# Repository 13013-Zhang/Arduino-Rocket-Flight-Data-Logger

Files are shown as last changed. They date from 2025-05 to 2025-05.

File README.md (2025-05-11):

**Read this in other languages: [English](README.md), [中文](README_ZH.md).**

# 🚀 Arduino-Based Water Rocket Flight Data Logger

An Arduino-powered, high-precision water rocket system designed to collect and log complete flight data from launch to landing. The system uses sensor fusion and filtering algorithms, features automatic parachute deployment, and includes an audio signal upon landing. Compatible with the real-time data visualization platform.

## 🧠 Features

- Sensor fusion using **MPU6050 (I2C)** and **BME280 (SPI)** for flight dynamics and environment data
- **Kalman filter** for angle estimation and **BMP (barometric method)** for altitude correction
- **Millisecond-interval data logging** to SD card with uniform timestamps for detailed analysis
- Real-time data visualization support
- **Automatic parachute deployment** at apogee or when the rocket tilts more than 120° (confirmed 3 times to avoid false triggers)
- **Buzzer alert** activated upon landing to assist in rocket retrieval

## 🛠️ Hardware Wiring
```
MPU6050: (I2C)
VCC      -> 3.3V
SCL      -> A5
SDA      -> A4
AD0      -> GND

BME280: (SPI)
VCC  -> 3.3V
SCK  -> D13
MISO -> D12
MOSI -> D11
CS   -> D9

SD Card: (SPI)
VCC  -> 5V
CS   -> D10
MOSI -> D11
MISO -> D12
SCK  -> D13

Servo:
PWM  -> D3
VCC  -> 5V
GND  -> GND

Buzzer:
+    -> D2
GND  -> GND 

LM35:
OUT -> A0
VCC -> 5V
GND -> GND
```

## 📦 Software Capabilities

- ✅ Real-time logging of: orientation angles (x, y, z), acceleration, pressure, altitude, temperature, and timestamp  
- ✅ Kalman filtering for stable angle output from MPU6050  
- ✅ BMP correction for accurate altitude using BME280  
- ✅ Apogee and tilt-based parachute logic (60° open, 90° closed)  
- ✅ Buzzer activation after landing (based on altitude and motion detection)  
- ✅ All data saved in CSV format on SD card  
- ✅ Compatible with Vofa+ desktop tool for visualization

## 📂 Data Format (Saved on SD Card)

Example (logged at consistent millisecond intervals):
| Time(ms) | Temp(C) | Pressure(hPa) | Alt(m) | FiltAlt(m) | AccX(g) | AccY(g) | AccZ(g) | GyroX(deg/s) | GyroY(deg/s) | GyroZ(deg/s) | AngleX(deg) | AngleY(deg) | AngleZ(deg) | LM35Temp(C) |
|---|---|---|---|---|---|---|---|---|---|---|---|---|---|---|
| 0 | 21.94 | 1013.11 | 0.55 | 0.11 | 0 | -0.04 | 0.98 | 1.84 | -2.7 | 2.32 | 2.67 | -4.63 | 3.8 | 21.48 |

## ✅ Development & Compatibility

- IDE: Arduino IDE  
- All libraries can be installed via Library Manager  
- Supported Boards: Arduino UNO / Nano / Mega etc.  
- Upper Computer: Vofa+  

## 📸 Images and Demonstrations
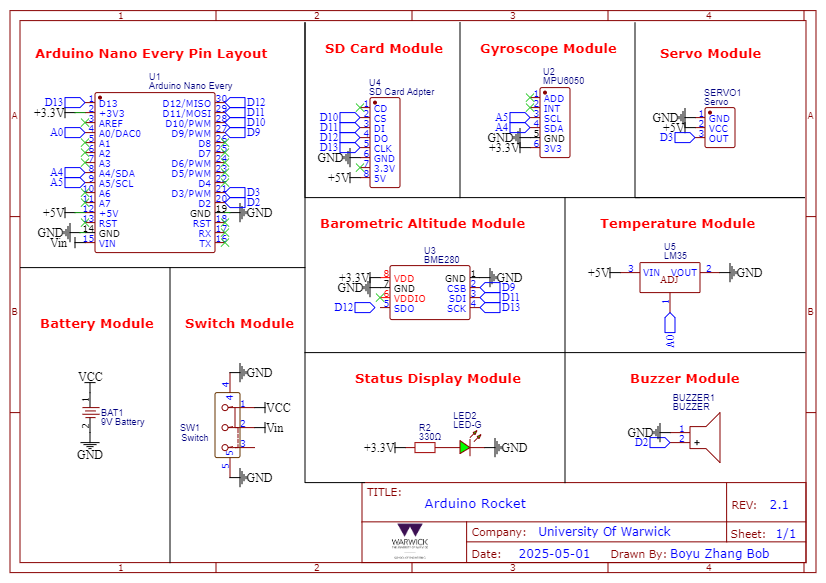
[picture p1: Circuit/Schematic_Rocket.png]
Schematic

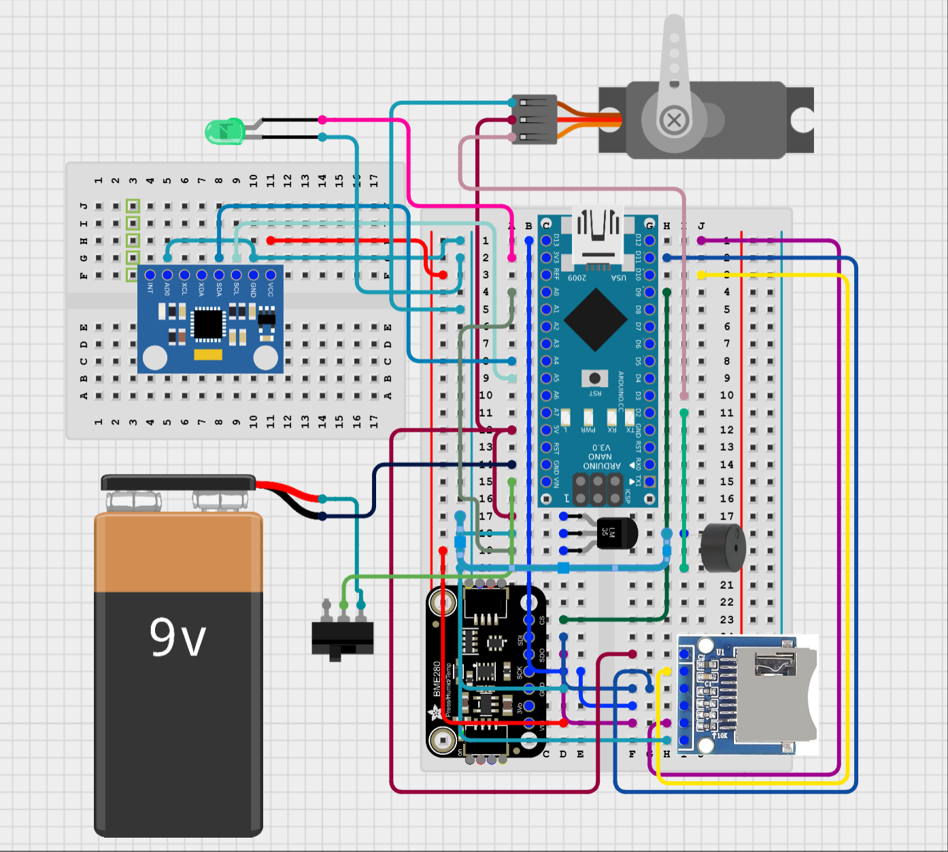
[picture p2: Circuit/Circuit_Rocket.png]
Circuit

<video controls src="Demonstration/Vofa+.mp4" title="Title"></video>

---

## 📄 License

This project is open-sourced under the MIT License. Feel free to use and modify it. Please provide attribution for commercial use.

---

## 🙌 Acknowledgments

This project was developed as part of the **ES192 Engineering Design** course at the **University of Warwick**.

Special thanks to my brilliant teammates for their dedication, teamwork, and creativity throughout the design, development, and testing phases:

- NGUYEN, Ryan  
- NIE, Jingren  
- CHAN, Rooney  
- JONES, Morgan  
- AL-DABAGH, Mouaid  
- HAQUE, Mayiz
- Boyu Zhang Bob (me)

We also extend our gratitude to the open-source hardware and software communities, whose tools and resources made this project possible.

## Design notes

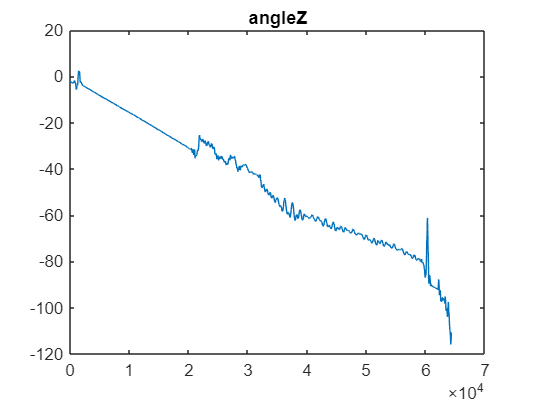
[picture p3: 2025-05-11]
Plots/angleZ.png

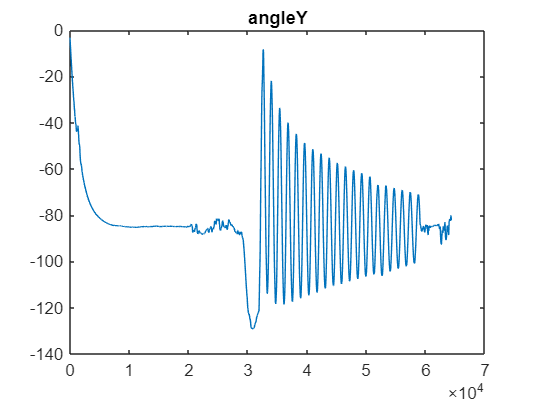
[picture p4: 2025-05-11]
Plots/AngleY.png

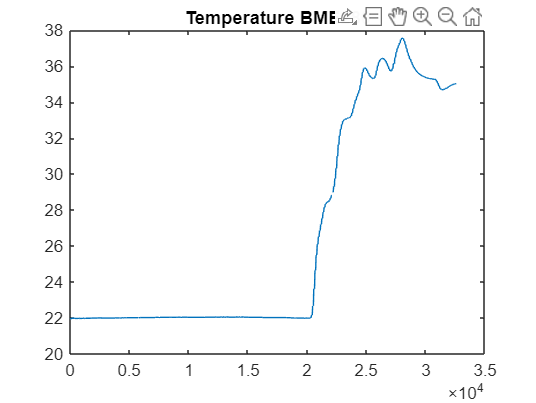
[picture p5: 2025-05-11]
Plots/Temperture BME.png

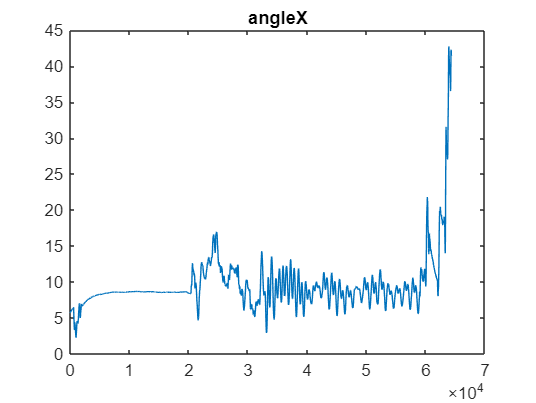
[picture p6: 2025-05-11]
Plots/angleX.png

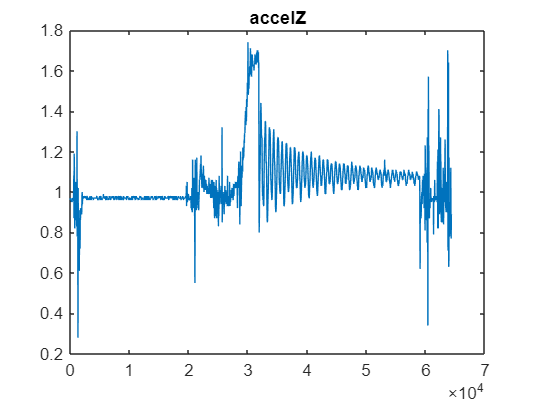
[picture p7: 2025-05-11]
Plots/accelZ.png

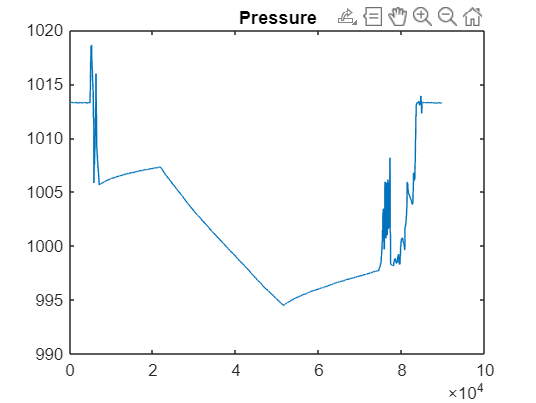
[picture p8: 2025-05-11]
Plots/Pressure.png

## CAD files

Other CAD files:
3D FIle/Front Wings.f3d

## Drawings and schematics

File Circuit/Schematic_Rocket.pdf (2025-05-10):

# +5VA⁰

Arduino Nano Every Pin Layout | SD Card Module | Gyroscope Module

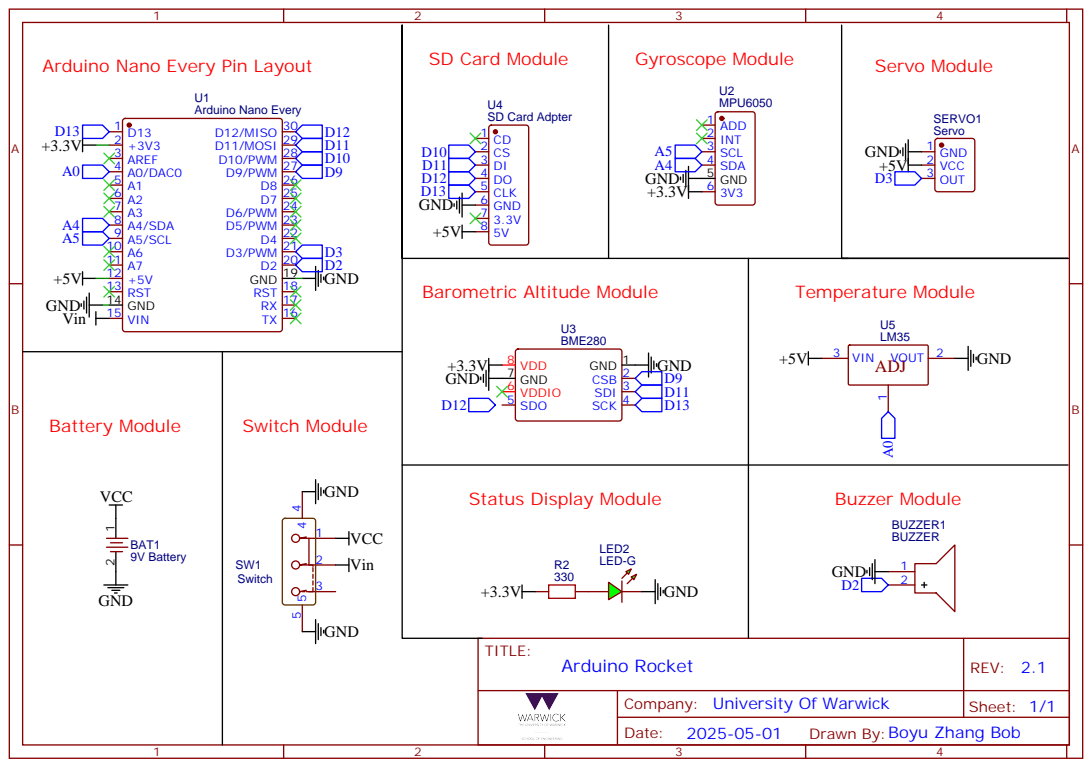
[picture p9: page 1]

Company: University Of Warwick

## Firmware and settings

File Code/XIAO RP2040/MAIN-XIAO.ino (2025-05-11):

/*
硬件连接定义 (基于XIAO RP2040引脚图):

MPU6050: (I2C)
VCC      -> 3.3V
SCL      -> D5 (P7 SCL)
SDA      -> D4 (P6 SDA)
AD0      -> GND

BME280: (SPI)
VCC  -> 3.3V
SCK  -> D8 (P2 SCK)
MISO -> D9 (P4 MISO)
MOSI -> D10 (P3 MOSI)
CS   -> D2 (P28 A2)

SD Card: (SPI)
VCC  -> 5V
CS   -> D7 (P1 CSn)
MOSI -> D10 (P3 MOSI)
MISO -> D9 (P4 MISO)
SCK  -> D8 (P2 SCK)

Servo:
PWM  -> D0 (P26 A0)
VCC  -> 5V
GND  -> GND

Buzzer:
+    -> D6 (P0 TX)
GND  -> GND 

LM35:
OUT -> A1 (P27 A1/D1)
VCC -> 5V
GND -> GND
*/

#include <Wire.h>
#include <SPI.h>
#include <SD.h>
#include <Servo.h>
#include <Adafruit_Sensor.h>
#include <Adafruit_BME280.h>
#include <MPU6050_light.h>

// 引脚定义
#define BME280_CS D2   // P28 A2
#define SD_CS D7       // P1 CSn
#define BUZZER_PIN D6  // P0 TX
#define SERVO_PIN D0   // P26 A0
#define LM35_PIN A1    // P27 A1/D1

// 传感器对象
Adafruit_BME280 bme(BME280_CS);  // SPI
MPU6050 mpu(Wire);
Servo parachuteServo;

// 文件对象
File dataFile;

// 校准数据
struct {
  float baseAlt;
  float initialRoll;
  float initialPitch;
  float initialYaw;
} calData;

// 状态变量
struct {
  bool isFlying = false;
  bool parachuteDeployed = false;
  bool landed = false;
  unsigned long startTime = 0;
  unsigned int landingChecks = 0;
  const unsigned int requiredLandingChecks = 3;
} flightState;

// 传感器数据结构
struct {
  unsigned long time;
  float temperature;
  float pressure;
  float altitude;
  float filteredAltitude;
  float accelX, accelY, accelZ;
  float gyroX, gyroY, gyroZ;
  float angleX, angleY, angleZ;
  float lm35Temp;
} sensorData;

// 初始化MPU6050
void initMPU6050() {
  Wire.setSDA(D4);  // XIAO RP2040的SDA是D4 (P6)
  Wire.setSCL(D5);  // XIAO RP2040的SCL是D5 (P7)
  Wire.begin();

  byte status = mpu.begin();
  while (status != 0) {
    Serial.println("MPU6050连接失败，错误代码: " + String(status));
    delay(1000);
    status = mpu.begin();
  }
  Serial.println("MPU6050连接成功");

  Serial.println("校准MPU6050...请保持设备静止");
  delay(1000);
  mpu.calcOffsets(true, true);

  mpu.update();
  calData.initialRoll = mpu.getAngleX();
  calData.initialPitch = mpu.getAngleY();
  calData.initialYaw = mpu.getAngleZ();

  Serial.println("校准完成，初始姿态(度):");
  Serial.print("Roll: ");
  Serial.print(calData.initialRoll);
  Serial.print(", Pitch: ");
  Serial.print(calData.initialPitch);
  Serial.print(", Yaw: ");
  Serial.println(calData.initialYaw);
}

// 初始化BME280
void initBME280() {
  SPI.setRX(D9);   // MISO (P4)
  SPI.setTX(D10);  // MOSI (P3)
  SPI.setSCK(D8);  // SCK (P2)

  if (!bme.begin()) {
    Serial.println("BME280初始化失败，请检查接线!");
    while (1)
      ;
  }

  Serial.println("校准BME280基准高度...");
  float sumAlt = 0;
  for (int i = 0; i < 100; i++) {
    sumAlt += bme.readAltitude(1013.25);
    delay(10);
  }
  calData.baseAlt = sumAlt / 100;
  Serial.println("基准高度校准完成: " + String(calData.baseAlt) + "米");
}

// 初始化SD卡
bool initSDCard() {
  SPI.setRX(D9);   // MISO (P4)
  SPI.setTX(D10);  // MOSI (P3)
  SPI.setSCK(D8);  // SCK (P2)

  if (!SD.begin(SD_CS)) {
    Serial.println("SD卡初始化失败!");
    return false;
  }

  char filename[15];
  for (int i = 1; i < 1000; i++) {
    sprintf(filename, "flight%d.csv", i);
    if (!SD.exists(filename)) {
      dataFile = SD.open(filename, FILE_WRITE);
      if (dataFile) {
        dataFile.println("Time(ms),Temp(C),Pressure(hPa),Alt(m),FiltAlt(m),AccX(g),AccY(g),AccZ(g),GyroX(deg/s),GyroY(deg/s),GyroZ(deg/s),AngleX(deg),AngleY(deg),AngleZ(deg),LM35Temp(C)");
        dataFile.flush();
        return true;
      }
    }
  }
  return false;
}

// 读取传感器数据
void readSensors() {
  static float prevAlt = 0;
  static unsigned long lastAltTime = 0;

  sensorData.time = millis() - flightState.startTime;

  mpu.update();
  sensorData.accelX = mpu.getAccX();
  sensorData.accelY = mpu.getAccY();
  sensorData.accelZ = mpu.getAccZ();
  sensorData.gyroX = mpu.getGyroX();
  sensorData.gyroY = mpu.getGyroY();
  sensorData.gyroZ = mpu.getGyroZ();
  sensorData.angleX = mpu.getAngleX() - calData.initialRoll;
  sensorData.angleY = mpu.getAngleY() - calData.initialPitch;
  sensorData.angleZ = mpu.getAngleZ() - calData.initialYaw;

  sensorData.temperature = bme.readTemperature();
  sensorData.pressure = bme.readPressure() / 100.0;

  float currentAlt = bme.readAltitude(1013.25) - calData.baseAlt;
  unsigned long currentTime = millis();
  float dt = (currentTime - lastAltTime) / 1000.0;

  if (dt > 0) {
    sensorData.filteredAltitude = 0.8 * prevAlt + 0.2 * currentAlt;
    prevAlt = sensorData.filteredAltitude;
    lastAltTime = currentTime;
  }

  sensorData.altitude = currentAlt;
  sensorData.lm35Temp = analogRead(LM35_PIN) * (3.3 / 4096.0) * 100;  // 12位ADC，3.3V参考
}

// 写入数据到SD卡
void writeDataToSD() {
  if (dataFile) {
    dataFile.print(sensorData.time);
    dataFile.print(",");
    dataFile.print(sensorData.temperature);
    dataFile.print(",");
    dataFile.print(sensorData.pressure);
    dataFile.print(",");
    dataFile.print(sensorData.altitude);
    dataFile.print(",");
    dataFile.print(sensorData.filteredAltitude);
    dataFile.print(",");
    dataFile.print(sensorData.accelX);
    dataFile.print(",");
    dataFile.print(sensorData.accelY);
    dataFile.print(",");
    dataFile.print(sensorData.accelZ);
    dataFile.print(",");
    dataFile.print(sensorData.gyroX);
    dataFile.print(",");
    dataFile.print(sensorData.gyroY);
    dataFile.print(",");
    dataFile.print(sensorData.gyroZ);
    dataFile.print(",");
    dataFile.print(sensorData.angleX);
    dataFile.print(",");
    dataFile.print(sensorData.angleY);
    dataFile.print(",");
    dataFile.print(sensorData.angleZ);
    dataFile.print(",");
    dataFile.println(sensorData.lm35Temp);
    dataFile.flush();
  }
}

// 发送数据到串口
void sendDataToSerial() {
  Serial.print(sensorData.time);
  Serial.print(",");
  Serial.print(sensorData.temperature);
  Serial.print(",");
  Serial.print(sensorData.pressure);
  Serial.print(",");
  Serial.print(sensorData.altitude);
  Serial.print(",");
  Serial.print(sensorData.filteredAltitude);
  Serial.print(",");
  Serial.print(sensorData.accelX);
  Serial.print(",");
  Serial.print(sensorData.accelY);
  Serial.print(",");
  Serial.print(sensorData.accelZ);
  Serial.print(",");
  Serial.print(sensorData.gyroX);
  Serial.print(",");
  Serial.print(sensorData.gyroY);
  Serial.print(",");
  Serial.print(sensorData.gyroZ);
  Serial.print(",");
  Serial.print(sensorData.angleX);
  Serial.print(",");
  Serial.print(sensorData.angleY);
  Serial.print(",");
  Serial.print(sensorData.angleZ);
  Serial.print(",");
  Serial.println(sensorData.lm35Temp);
}

// 检查飞行状态
void checkFlightStatus() {
  static float maxAltitude = 0;
  static bool descending = false;
  static int angleChecks = 0;
  static float prevAlt = 0;
  static unsigned long lastCheckTime = 0;

  if (!flightState.isFlying && (abs(sensorData.accelZ) > 1.5 || abs(sensorData.accelY) > 1.5 || abs(sensorData.accelX) > 1.5)) {
    flightState.isFlying = true;
    dataFile.println("检测到起飞!");
    dataFile.flush();
    Serial.println("检测到起飞!");
  }

  if (flightState.isFlying && !flightState.landed) {
    if (sensorData.filteredAltitude > maxAltitude) {
      maxAltitude = sensorData.filteredAltitude;
      descending = false;
    } else if (sensorData.filteredAltitude < maxAltitude - 2.0) {
      descending = true;
    }

    float tiltAngle = sqrt(sensorData.angleX * sensorData.angleX + sensorData.angleY * sensorData.angleY);
    if (tiltAngle > 120) {
      angleChecks++;
    } else {
      angleChecks = 0;
    }

    if (!flightState.parachuteDeployed && ((descending && sensorData.filteredAltitude < maxAltitude * 0.9) || angleChecks >= 3)) {
      parachuteServo.write(90);
      flightState.parachuteDeployed = true;
      dataFile.println("降落伞已打开!");
      dataFile.flush();
      Serial.println("降落伞已打开!");
    }

    unsigned long currentTime = millis();
    float dt = (currentTime - lastCheckTime) / 1000.0;
    if (dt > 0.1) {
      float altChangeRate = (sensorData.filteredAltitude - prevAlt) / dt;

      if (abs(altChangeRate) < 0.5 && abs(sensorData.accelZ - 1.0) < 0.3) {
        flightState.landingChecks++;
      } else {
        flightState.landingChecks = 0;
      }

      prevAlt = sensorData.filteredAltitude;
      lastCheckTime = currentTime;
    }

    if (flightState.landingChecks >= flightState.requiredLandingChecks && flightState.parachuteDeployed == true) {
      flightState.landed = true;
      digitalWrite(BUZZER_PIN, HIGH);
      dataFile.println("检测到着陆!");
      dataFile.flush();
      Serial.println("检测到着陆!");
    }
  }

  if (flightState.landed) {
    static unsigned long lastBeepTime = 0;
    if (millis() - lastBeepTime >= 100) {
      digitalWrite(BUZZER_PIN, !digitalRead(BUZZER_PIN));
      lastBeepTime = millis();
    }
  }
}

void setup() {
  Serial.begin(115200);
  while (!Serial)
    ;
  pinMode(23, INPUT);

  pinMode(BUZZER_PIN, OUTPUT);
  parachuteServo.attach(SERVO_PIN);
  parachuteServo.write(60);

  initMPU6050();
  initBME280();

  if (!initSDCard()) {
    Serial.println("SD卡初始化失败，数据将仅输出到串口");
  }

  flightState.startTime = millis();
  Serial.println("系统初始化完成，准备就绪");
}

void loop() {
  static unsigned long lastLogTime = 0;

  if (millis() - lastLogTime >= 10) {
    readSensors();
    writeDataToSD();
    // sendDataToSerial();
    checkFlightStatus();
    lastLogTime = millis();
  }
}

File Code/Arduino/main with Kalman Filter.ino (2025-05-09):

/*
MPU6050: (I2C)
VCC  -> 3.3V
SCL  -> A5
SDA  -> A4
AD0  -> GND

BME280: (SPI)
VCC  -> 3.3V
SCK  -> D13
MISO -> D12
MOSI -> D11
CS   -> D9

SD Card: (SPI)
VCC  -> 5V
CS   -> D10
MOSI -> D11
MISO -> D12
SCK  -> D13

Servo:
PWM  -> D3
VCC  -> 5V
GND  -> GND

Buzzer:
VCC  -> D2
GND  -> GND 

LM35:
OUT -> A0
VCC -> 5V
GND -> GND
*/

#include <Wire.h>
#include <SPI.h>
#include <SdFat.h>
#include <Servo.h>
#include <Adafruit_Sensor.h>
#include <Adafruit_BME280.h>
#include <MPU6050_light.h>

// Pins
#define BME280_CS 9
#define SD_CS 10
#define BUZZER_PIN 2
#define SERVO_PIN 3
#define LM35_PIN A0
#define LED 5

// Sensors
Adafruit_BME280 bme(BME280_CS);
MPU6050 mpu(Wire);
Servo parachuteServo;
SdFat SD;
File dataFile;

// Calibration and state
float basePressure = 101325.0;
float seaLevelPressure = 1013.25;
float kalmanAngleX = 0, kalmanAngleY = 0;
float kalmanAltitude = 0;
float velocity = 0;

float angleErrorCov = 1, altitudeErrorCov = 1;
float angleEstimateCov = 1, altitudeEstimateCov = 1;

unsigned long lastKalmanTime = 0;
float altitudeVelocity = 0;

struct {
  float baseAlt;
  float initialRoll;
  float initialPitch;
  float initialYaw;
} calData;

struct {
  bool isFlying = false;
  bool parachuteDeployed = false;
  bool landed = false;
  unsigned long startTime = 0;
  unsigned int landingChecks = 0;
  const unsigned int requiredLandingChecks = 3;
} flightState;

struct {
  unsigned long time;
  float temperature;
  float pressure;
  float altitude;
  float filteredAltitude;
  float accelX, accelY, accelZ;
  float gyroX, gyroY, gyroZ;
  float angleX, angleY, angleZ;
  float lm35Temp;
} sensorData;

// Kalman filter for angle (1D)
float kalmanFilterAngle(float newAngle, float gyroRate, float dt) {
  float Q_angle = 0.001, Q_gyro = 0.003, R_angle = 0.03;
  static float bias = 0;
  static float rate = 0;
  static float P[2][2] = { { 0, 0 }, { 0, 0 } };
  static float angle = 0;

  rate = gyroRate - bias;
  angle += dt * rate;

  P[0][0] += dt * (dt * P[1][1] - P[0][1] - P[1][0] + Q_angle);
  P[0][1] -= dt * P[1][1];
  P[1][0] -= dt * P[1][1];
  P[1][1] += Q_gyro * dt;

  float S = P[0][0] + R_angle;
  float K[2];
  K[0] = P[0][0] / S;
  K[1] = P[1][0] / S;

  float y = newAngle - angle;
  angle += K[0] * y;
  bias += K[1] * y;

  float P00_temp = P[0][0], P01_temp = P[0][1];

  P[0][0] -= K[0] * P00_temp;
  P[0][1] -= K[0] * P01_temp;
  P[1][0] -= K[1] * P00_temp;
  P[1][1] -= K[1] * P01_temp;

  return angle;
}

// BMP altitude via pressure (ISA standard)
float pressureToAltitude(float pressure) {
  return 44330.0 * (1.0 - pow(pressure / (seaLevelPressure * 100), 0.1903));
}

void initMPU6050() {
  Wire.begin();
  byte status = mpu.begin();
  while (status != 0) {
    Serial.println("MPU6050 Connection failed, Error code: " + String(status));
    delay(1000);
    status = mpu.begin();
  }
  Serial.println("MPU6050 Connection successful");
  delay(1000);
  mpu.calcOffsets(true, true);
  mpu.update();
  calData.initialRoll = mpu.getAngleX();
  calData.initialPitch = mpu.getAngleY();
  calData.initialYaw = mpu.getAngleZ();
}

void initBME280() {
  if (!bme.begin()) {
    Serial.println("BME280 initialization failed!");
    while (1)
      ;
  }
  float sum = 0;
  for (int i = 0; i < 100; i++) {
    sum += pressureToAltitude(bme.readPressure());
    delay(10);
  }
  calData.baseAlt = sum / 100;
}

bool initSDCard() {
  if (!SD.begin(SD_CS, SPI_FULL_SPEED)) return false;
  char filename[15];
  for (int i = 1; i < 1000; i++) {
    sprintf(filename, "flight%d.csv", i);
    if (!SD.exists(filename)) {
      dataFile = SD.open(filename, FILE_WRITE);
      if (dataFile) {
        dataFile.println("Time(ms),Temp(C),Pressure(hPa),Alt(m),FiltAlt(m),AccX(g),AccY(g),AccZ(g),GyroX(deg/s),GyroY(deg/s),GyroZ(deg/s),AngleX(deg),AngleY(deg),AngleZ(deg),LM35Temp(C)");
        dataFile.flush();
        return true;
      }
    }
  }
  return false;
}

void readSensors() {
  unsigned long now = millis();
  float dt = (now - lastKalmanTime) / 1000.0;
  if (dt <= 0) dt = 0.01;
  lastKalmanTime = now;

  mpu.update();
  float angleXraw = mpu.getAngleX() - calData.initialRoll;
  float angleYraw = mpu.getAngleY() - calData.initialPitch;

  kalmanAngleX = kalmanFilterAngle(angleXraw, mpu.getGyroX(), dt);
  kalmanAngleY = kalmanFilterAngle(angleYraw, mpu.getGyroY(), dt);

  sensorData.accelX = mpu.getAccX();
  sensorData.accelY = mpu.getAccY();
  sensorData.accelZ = mpu.getAccZ();
  sensorData.gyroX = mpu.getGyroX();
  sensorData.gyroY = mpu.getGyroY();
  sensorData.gyroZ = mpu.getGyroZ();
  sensorData.angleX = kalmanAngleX;
  sensorData.angleY = kalmanAngleY;
  sensorData.angleZ = mpu.getAngleZ() - calData.initialYaw;

  sensorData.pressure = bme.readPressure();
  float currentAlt = pressureToAltitude(sensorData.pressure) - calData.baseAlt;

  float Q = 0.01, R = 2;
  float P = altitudeEstimateCov + Q;
  float K = P / (P + R);
  kalmanAltitude += K * (currentAlt - kalmanAltitude);
  altitudeEstimateCov = (1 - K) * P;

  sensorData.altitude = currentAlt;
  sensorData.filteredAltitude = kalmanAltitude;
  sensorData.temperature = bme.readTemperature();
  sensorData.lm35Temp = analogRead(LM35_PIN) * (5.0 / 1024.0) * 100;
  sensorData.time = now - flightState.startTime;
}

void writeDataToSD() {
  if (!dataFile) return;
  dataFile.print(sensorData.time);
  dataFile.print(",");
  dataFile.print(sensorData.temperature);
  dataFile.print(",");
  dataFile.print(sensorData.pressure / 100.0);
  dataFile.print(",");
  dataFile.print(sensorData.altitude);
  dataFile.print(",");
  dataFile.print(sensorData.filteredAltitude);
  dataFile.print(",");
  dataFile.print(sensorData.accelX);
  dataFile.print(",");
  dataFile.print(sensorData.accelY);
  dataFile.print(",");
  dataFile.print(sensorData.accelZ);
  dataFile.print(",");
  dataFile.print(sensorData.gyroX);
  dataFile.print(",");
  dataFile.print(sensorData.gyroY);
  dataFile.print(",");
  dataFile.print(sensorData.gyroZ);
  dataFile.print(",");
  dataFile.print(sensorData.angleX);
  dataFile.print(",");
  dataFile.print(sensorData.angleY);
  dataFile.print(",");
  dataFile.print(sensorData.angleZ);
  dataFile.print(",");
  dataFile.println(sensorData.lm35Temp);
  dataFile.flush();
}
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
